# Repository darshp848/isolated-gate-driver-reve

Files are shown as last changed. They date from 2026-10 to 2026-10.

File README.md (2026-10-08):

# Six-channel isolated gate driver — Rev E

An Altium PCB for controlling six floating transistor gates from a low-voltage PWM controller. Each channel has its own isolated bias supply and UCC5310M gate driver; a shared AHCT buffer interfaces the PWM logic. Designed by Darsh Patel, with Claude and Codex assisting the design iteration, layout transfer, review and documentation.

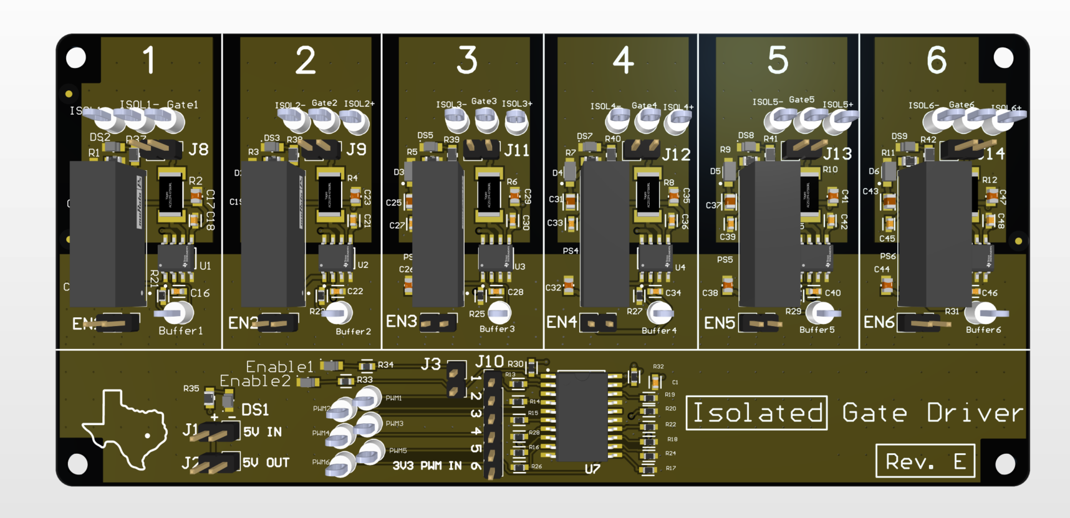
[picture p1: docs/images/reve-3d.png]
Rev E Altium 3D view supplied by Darsh Patel


*Rev E 3D CAD view. Model markings and catalog values may be placeholders; see the component-selection notes below.*

**This is the saved Rev E design snapshot, not a qualified manufacturing release. Some CAD components were selected only for their footprint, schematic symbol and 3D model. Their displayed values, descriptions and manufacturer part numbers are not necessarily the intended electrical parts. Do not order or assemble directly from the exported CAD BOM.** See [component selection and placeholders](docs/component-selection.md).

## Files

| Path | Contents |
| --- | --- |
| `hardware/isolated-gate-driver.PrjPcb` | Standalone Altium project with local document paths |
| `hardware/Sheet2.SchDoc` | Native schematic, unchanged from the source |
| `hardware/PCB2.PcbDoc` | Native four-layer board, silk marked **Rev. E**, unchanged from the source |
| `hardware/libraries/GPIO_Headers.PcbLib` | Project-local 2.54 mm header footprints and models |
| [Architecture](docs/architecture.md) | Signal path, bias supplies, gate drive and design reasoning |
| [Component selection](docs/component-selection.md) | Explicit placeholder examples and commissioning selections |
| [Opening the design](docs/opening-the-design.md) | Altium version, library links and export workflow |
| [Revision and validation](docs/revision-and-validation.md) | What was checked, historical evidence and remaining work |
| [Source manifest](docs/source-manifest.json) | Source-relative paths, modification dates and SHA-256 hashes |
| [Placed footprints](docs/placed-footprints.csv) | Actual footprint names and positions from the saved PCB |

## Status

The snapshot was packaged October 8, 2026, including the user's newly saved Rev E silkscreen correction that day. The schematic was saved October 3. There are 152 unique schematic designators and 155 PCB component records, including three PCB fiducials. Original design binaries are preserved byte-for-byte. Only the project wrapper was adjusted to remove external file paths and references to omitted generated outputs.

October 3 routing/DRC results predate Rev E's October 7–8 edits and do not certify this snapshot. No fresh Altium compile, ECO comparison, repour, DRC or bench qualification was performed for this publication. Old fabrication ZIPs are deliberately excluded; regenerate outputs from the reviewed final design. No complete order-ready Rev E BOM is supplied.

## Purpose

The board separates a controller's PWM commands from six independently referenced gate circuits. It can support experiments with different bridge configurations without putting a processor on the driver board. The external controller and power stage remain responsible for PWM sequencing, dead time, current protection and fault shutdown. Transistor choice, bus voltage, gate charge and switching frequency determine the actual operating envelope.

Functional architecture

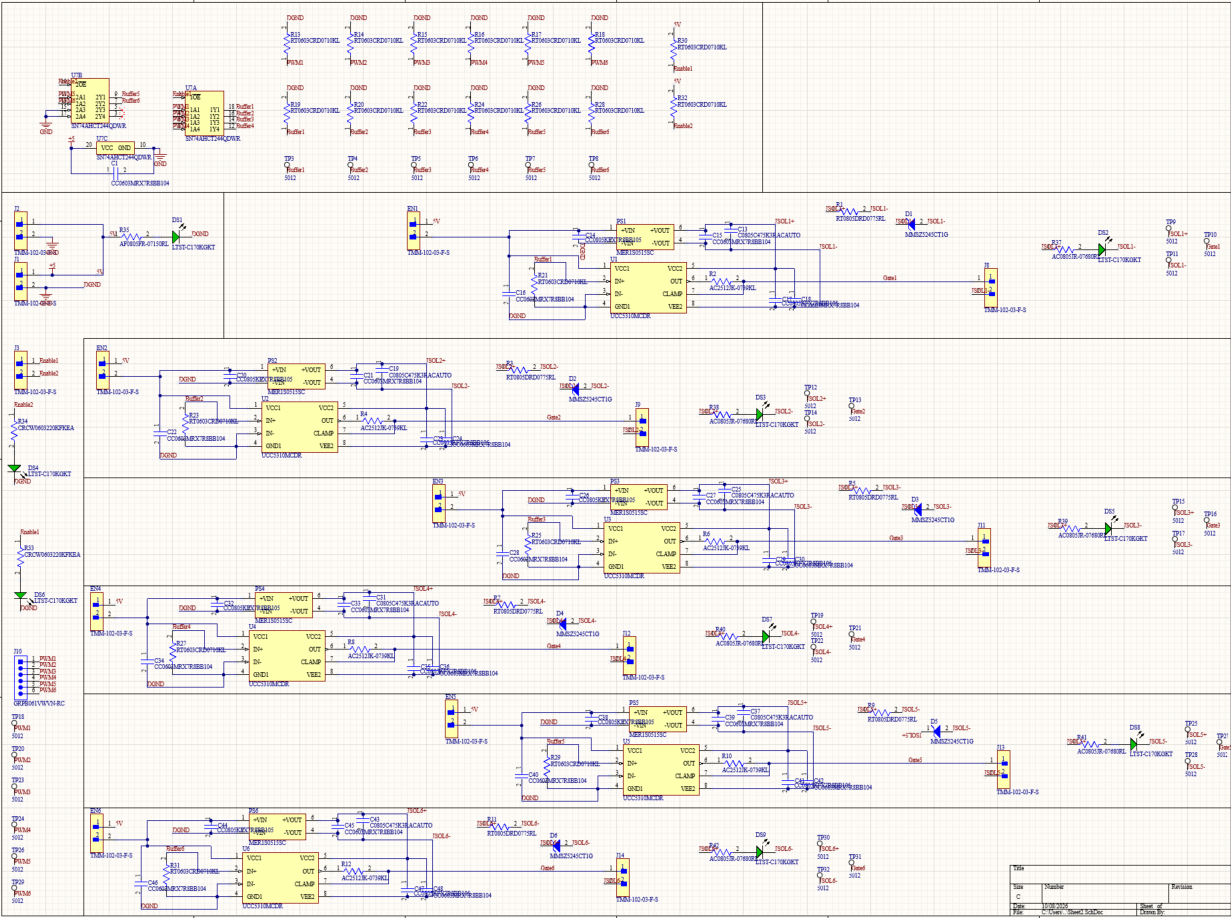
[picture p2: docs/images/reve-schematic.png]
Rev E schematic supplied by Darsh Patel


*Rev E schematic: shared PWM buffer and enable circuitry with six isolated supply and gate-driver channels. Click the image to inspect it at full resolution. Some component values and part numbers are CAD placeholders; use the component-selection notes when interpreting them.*

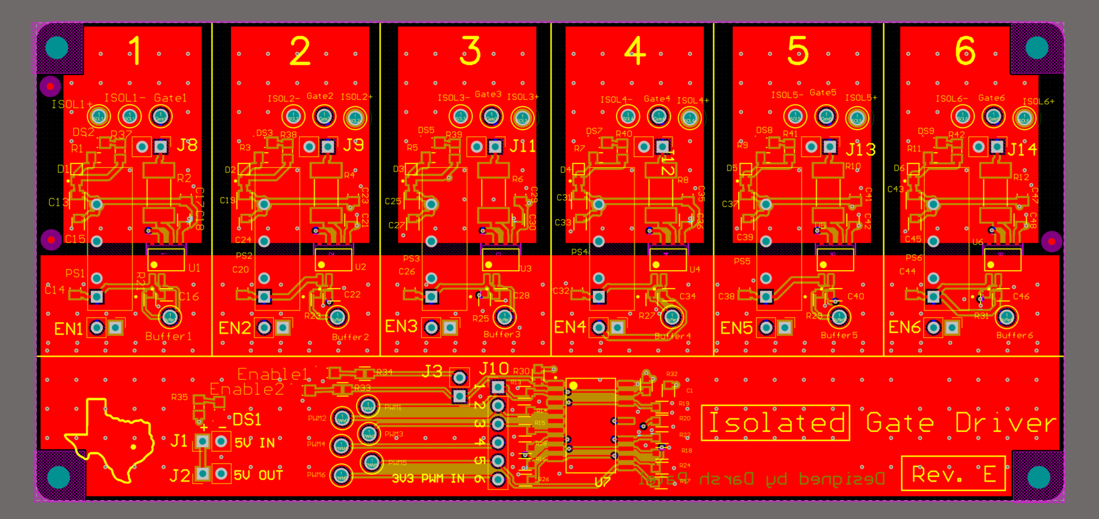
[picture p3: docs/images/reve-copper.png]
Rev E copper and silkscreen view supplied by Darsh Patel


*User-supplied Altium copper view, showing six channel columns and the shared PWM interface. This image is documentation, not a DRC or isolation qualification report.*

The use of isolated driver ICs does not establish an assembled-board safety isolation or working-voltage rating. The converter, PCB stackup, copper spacing, connectors and test arrangement must all meet the intended application. Refer to the [validation record](docs/revision-and-validation.md) before using the design.

## License and attribution

The original circuit/layout contributions and documentation are released under the [MIT license](LICENSE). This grant does not relicense vendor CAD content embedded in the native files. The converted KiCad header library retains its upstream license; see [third-party notices](THIRD_PARTY_NOTICES.md). Manufacturer names identify the parts and do not imply endorsement. AI assistance is documented as development provenance, not evidence of electrical validation.

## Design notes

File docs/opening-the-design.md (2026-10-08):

# Opening and exporting the design

The source workflow used Altium Designer 26; the October layout transfer recorded **26.10.1.5**. Open `hardware/isolated-gate-driver.PrjPcb`. It references the schematic, PCB and local GPIO header library using relative paths.

The original project linked to `../../3-phase-inverter/Sheet2.SchDoc` and `PCB2.PcbDoc`. A much smaller PCB2 file beside the original project was an older/unrelated board. That duplicate is not included. Stale ActiveBOM, PDN analysis, output-job and generated-report entries were removed from the project wrapper. Native schematic and board files were not edited.

Placed symbols, footprints and PCB 3D body data are preserved in the native documents. The header library is included separately for reuse. Some schematic model links still refer to the original machine's library paths or managed component sources; placed content can be inspected, but library update/replacement may require relinking `GPIO_Headers.PcbLib` and obtaining the appropriate upstream vendor libraries. The package does not claim a complete portable library for replacing every part.

Do not run an automatic library update simply to open the design. Resolve intended parts first, especially the metadata/footprint mismatches documented in [component selection](component-selection.md).

## Validation and outputs

Work in a copy of the repository. Compile the project, inspect messages, compare every schematic pin with its PCB pad net, and inspect ECO changes before applying them. Review all four copper layers, isolation-domain spacing, gate loops and return paths. Repour and run fresh native DRC on the final saved board.

Create new output jobs for the reviewed revision: schematic PDF, assembly BOM with DNP flags, pick-and-place file, fabrication drawings, Gerbers and drill files. Inspect the generated layers independently. This snapshot includes no Rev E Gerber release; prior October 4 ZIPs precede the latest board save.

The project organization follows [Altium project documentation](https://www.altium.com/documentation/altium-designer/creating-projects-documents). Output generation remains a separate review step in Altium.

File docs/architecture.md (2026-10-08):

# How the board works

## Signal and supply paths

Six PWM commands enter J10. U7 is an SN74AHCT244 octal non-inverting buffer operated from the control-side 5 V rail. Its TTL-compatible inputs provide an interface for 3.3 V PWM logic; its outputs feed the six UCC5310MCDR IN+ pins. The UCC inputs are CMOS, so using the buffer avoids depending on a marginal direct 3.3 V high level at a 5 V driver input supply. U7 has two independently controlled active-low output-enable banks. See [TI's buffer documentation](https://www.ti.com/product/SN74AHCT244).

Each channel's EN header interrupts the **5 V feed to that channel's driver logic supply and DC/DC converter**. It is a supply-selection jumper, distinct from J3's logic enables. Removing bias power is not a substitute for a characterized fast fault shutdown.

PS1–PS6 are MER1S0515SC unregulated isolated converters. They derive nominal 15 V floating rails from the channel's 5 V input. Each UCC5310 output is referenced to its own ISOLn− return, so the gate output can follow a floating transistor source/emitter. Keep each gate and return together; do not combine isolated returns merely because the connectors look identical.

The series gate resistors control charging/discharging current and switching behavior. The UCC5310M's CLAMP pin connects to the gate-side node after that resistor in the saved schematic diagnostic. Its active Miller clamp is intended to shunt off-state Miller current to the local return. Cable and PCB loop inductance still matter. See [TI's UCC5310 documentation](https://www.ti.com/product/UCC5310).

## Interface map

This map was derived from the **saved October 3 schematic**, using a read-only endpoint/label diagnostic. It is not an Altium-compiled netlist or verification of every October 7 PCB pad. The diagnostic's complete pin groups are in [saved-schematic-pin-groups.json](saved-schematic-pin-groups.json). Confirm the interface against final compiled nets and PCB pads before connecting hardware.

| Connector | Saved schematic connection |
| --- | --- |
| J1, J2 | Pin 1: control 5 V; pin 2: DGND. Parallel access to the same supply. |
| J10 | Pins 1–6: PWM1–PWM6. No control ground pin on this header. |
| J3 | Pin 1: U7 OE1, controlling PWM1–4; pin 2: U7 OE2, controlling PWM5–6. High disables, low enables. |
| EN1–EN6 | Pin 1: shared 5 V; pin 2: corresponding UCC VCC1 and converter +VIN. A shunt supplies that channel. |
| J8, J9 | Pin 1: Gate1/Gate2; pin 2: corresponding ISOL1−/ISOL2−. |
| J11, J12 | Pin 1: Gate3/Gate4; pin 2: corresponding isolated return. |
| J13, J14 | Pin 1: Gate5/Gate6; pin 2: corresponding isolated return. |

R13–R18 pull the PWM inputs toward DGND. Resistors also pull the buffered driver-input commands toward DGND. R30/R32 pull U7's OE nodes toward 5 V; those nodes also feed indicator branches through R33/R34. This is a later schematic change from the September audit, which reported OE bias resistors absent. A controller interface to the 5 V-biased OE pins must be selected and checked for its actual tolerances and power sequencing.

## Bias, indicators and protection footprints

The odd-numbered R1–R11 preloads span each floating rail. The earlier selected 2 kΩ preload draws 7.5 mA and dissipates 0.1125 W at 15 V. This helps maintain a minimum load on an unregulated converter; it is not an inrush limiter or precision regulator. Indicator branches add further rail loading. Their resistor fields also require reconciliation with the assembly selection.

D1–D6 span the isolated rails, cathode toward the positive rail. These optional Zener footprints permit evaluation of rail limiting; their nominal voltage is not a guaranteed transient ceiling. Initial DNP and the proposed 18 V candidate remain documented in [component selection](component-selection.md).

Gate-drive energy per cycle is approximately Qg × Vgate, giving an average gate-charge current near Qg × switching frequency. Converter capacity must cover that demand plus driver quiescent current, preload and indicators. The final resistor also needs pulse and thermal assessment. These estimates guide component selection; they do not establish a tested frequency rating.

The MER1 family has minimum-load and insulation limitations. Its nominal output and isolation test figures must not be treated as a regulated rail specification or whole-board working-voltage rating. Use the [Murata MER1 datasheet](https://www.murata.com/products/productdata/8807029833758/kdc-mer1.pdf) for the selected part and actual application.

## Layout and system responsibilities

The layout uses six repeated channel areas and a common control section on a four-layer board. The October transfer replaced small-pitch catalog header footprints with standard 2.54 mm headers and corrected their 3D-body positions. Preserve actual pad numbering and isolation-domain boundaries when editing.

A short, paired gate/Kelvin-return path reduces ringing and false turn-on risk. Isolation must be reviewed across all copper layers, not just the visible top-layer gap. Controller-side ground, floating channel returns and bench-instrument references need an intentional grounding arrangement.

The PCB contains no processor or autonomous PWM interlock. Dead time, complementary-switch assignment, current sensing, fault shutdown and startup/reset behavior belong to the complete system. An active-low buffer enable is useful command inhibition, but is not a fully qualified power-stage protection scheme.

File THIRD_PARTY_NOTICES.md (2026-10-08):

# Third-party CAD content

The root MIT grant covers Darsh Patel's original design contributions and this repository's documentation. Vendor names, datasheets, catalog parameters, downloaded schematic symbols and embedded CAD/3D models retain their respective owners' rights and terms; no new license is asserted over those assets. Unrelated downloaded-part library collections are not included.

## GPIO header library

`hardware/libraries/GPIO_Headers.PcbLib` is the Altium conversion of KiCad standard `PinHeader_1x02_P2.54mm_Vertical` and `PinHeader_1x06_P2.54mm_Vertical` footprints and associated header models, with model-position corrections made during the Altium transfer. Attribution: KiCad library contributors; Altium conversion/placement corrections during Darsh Patel's project with Codex assistance.

The KiCad library data is distributed under **CC-BY-SA 4.0 with the KiCad electronic-design exception**. Redistribution of library collections retains that license. See [KiCad's license and exception](https://www.kicad.org/libraries/license/) and [CC-BY-SA 4.0 legal text](https://creativecommons.org/licenses/by-sa/4.0/legalcode). The root MIT license does not replace this library license.

Manufacturer documentation is referenced by links, rather than redistributed as datasheet collections.

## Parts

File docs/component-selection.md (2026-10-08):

# Component values, footprints and assembly selection

The schematic and PCB contain parts chosen to obtain a suitable **footprint, schematic symbol or 3D CAD model**. A placeholder may have the correct package but the wrong resistance, power rating, voltage rating, product description or manufacturer part number. A familiar package name is not a component specification.

The native files are published as saved, including this metadata. This repository does not silently rewrite their values or imply that every catalog field is correct.

## Confirmed examples

| References | Metadata retained in CAD | Intended selection or disposition from the design discussions |
| --- | --- | --- |
| R1, R3, R5, R7, R9, R11 | RT0805DRD0775RL; 75 Ω, 0.125 W, 0805 | Rail preload: **2 kΩ, 0.5 W**, ERJ-P06F2001V in the earlier commissioning selection. Verify the final rail load and dissipation. |
| R2, R4, R6, R8, R10, R12 | AC2512JK-0739KL; 39 kΩ, 1 W, 2512 | Gate resistor: **10 Ω, 1 W**, AC2512FK-0710RL as a commissioning starting point. Tune with the actual transistor and switching measurements. |
| U7 | SN74AHCT244QDWR | Earlier procurement selection is SN74AHCT244DWR, DW SOIC-20. Confirm pinout, operating range and footprint for the actual ordered part. |
| D1–D6 | MMSZ5245CT1G, nominal 15 V rail Zener | Earlier procurement proposed MMSZ5248CT1G, nominal 18 V, as a **test candidate**, initially DNP. Neither nominal voltage establishes a safe gate-voltage ceiling. Population remains a qualification decision. |
| J1/J2/J3, J8/J9/J11–J14, EN1–EN6 | Several symbols retain 2 mm header descriptions/MPNs | The placed PCB uses **1×2, 2.54 mm pitch** headers. Order against the actual land pattern and mechanical requirements. |
| J10 | GRPB061VWVN-RC description retains 1.27 mm pitch | The placed PCB uses **1×6, 2.54 mm pitch**. The old symbol's MPN is not a valid purchasing instruction for that footprint. |
| R37–R42 | 680 Ω, 0.125 W indicator-resistor metadata | Later sourcing notes propose 2 kΩ. This is a recommendation requiring assembly reconciliation, not a confirmed populated value. |
| R33/R34 | 220 kΩ indicator-resistor metadata | Later sourcing notes propose 10 kΩ. This is a recommendation; check indicator loading of the OE nodes. |

These are confirmed discrepancies, not an exhaustive approved-parts list. The design also contains indicators and pull/bias components added in later iterations. Their values and exact procurement choices need reconciliation against the complete current schematic.

[CAD metadata CSV](cad-metadata-NOT-FOR-ORDER.csv) is supplied for inspection only. [Placed footprints CSV](placed-footprints.csv) lists the actual saved PCB patterns. Neither file is an approved assembly BOM. Earlier Rev C/D purchase quantities, stock allocation and spare counts have not been carried into this repository as a Rev E order.

## Preparing an assembly BOM

1. Select the actual transistor, its recommended gate voltage, gate charge and operating conditions.
2. Reconcile every designator with its circuit role, desired value, tolerance, voltage/power/pulse rating and population state.
3. Select the actual manufacturer part, then check pin numbering, package dimensions, pad geometry, orientation and 3D body. Matching package size alone is insufficient.
4. Update all schematic parameters and DNP flags, not just visible comments; review the schematic-to-PCB ECO before applying it.
5. Generate a new BOM and compare it by designator with the reviewed assembly plan. Generate fabrication and placement outputs from that same saved revision.

The 2 kΩ preload and 10 Ω gate resistor above are historical commissioning choices. They are not universal choices for every MOSFET, IGBT or SiC device.

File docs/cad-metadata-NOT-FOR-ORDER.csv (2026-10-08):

Designator | CAD comment / MPN (may be placeholder) | CAD description (may be placeholder) | Status
U1 | UCC5310MCDR | DGTL ISO 3KV 1CH GATE DRVR 8SOIC | CAD METADATA ONLY - NOT AN ASSEMBLY BOM
PS1 | MER1S0515SC | Module DC-DC 5VIN 1-OUT 15V 0.067A 1W 4-Pin SIP Tube | CAD METADATA ONLY - NOT AN ASSEMBLY BOM
R21 | RT0603CRD0710KL | RES SMD 10K OHM 0.25% 1/10W 0603 | CAD METADATA ONLY - NOT AN ASSEMBLY BOM
C16 | CC0603MRX7R8BB104 | CAP CER 0.1UF 25V X7R 0603 | CAD METADATA ONLY - NOT AN ASSEMBLY BOM
C14 | CC0805KFX7R8BB105 | CC0805 1 uF X7R 10.00% 25 V | CAD METADATA ONLY - NOT AN ASSEMBLY BOM
C13 | C0805C475K3RACAUTO | CAP CER 0805 4.7UF 25V X7R 10% | CAD METADATA ONLY - NOT AN ASSEMBLY BOM
C15 | CC0603MRX7R8BB104 | CAP CER 0.1UF 25V X7R 0603 | CAD METADATA ONLY - NOT AN ASSEMBLY BOM
C17 | CC0805KFX7R8BB105 | CC0805 1 uF X7R 10.00% 25 V | CAD METADATA ONLY - NOT AN ASSEMBLY BOM
C18 | CC0603MRX7R8BB104 | CAP CER 0.1UF 25V X7R 0603 | CAD METADATA ONLY - NOT AN ASSEMBLY BOM
J10 | GRPB061VWVN-RC | Male Header, Pitch 1.27 mm, 1 x 6 Position, Height 4 mm, Tail Length 2.3 mm, -40 to 105 degC, RoHS, Bulk | CAD METADATA ONLY - NOT AN ASSEMBLY BOM
J8 | TMM-102-03-F-S | CONN HEADER VERT 2POS 2MM | CAD METADATA ONLY - NOT AN ASSEMBLY BOM
J1 | TMM-102-03-F-S | CONN HEADER VERT 2POS 2MM | CAD METADATA ONLY - NOT AN ASSEMBLY BOM
U2 | UCC5310MCDR | DGTL ISO 3KV 1CH GATE DRVR 8SOIC | CAD METADATA ONLY - NOT AN ASSEMBLY BOM
PS2 | MER1S0515SC | Module DC-DC 5VIN 1-OUT 15V 0.067A 1W 4-Pin SIP Tube | CAD METADATA ONLY - NOT AN ASSEMBLY BOM
R23 | RT0603CRD0710KL | RES SMD 10K OHM 0.25% 1/10W 0603 | CAD METADATA ONLY - NOT AN ASSEMBLY BOM
C22 | CC0603MRX7R8BB104 | CAP CER 0.1UF 25V X7R 0603 | CAD METADATA ONLY - NOT AN ASSEMBLY BOM
C20 | CC0805KFX7R8BB105 | CC0805 1 uF X7R 10.00% 25 V | CAD METADATA ONLY - NOT AN ASSEMBLY BOM
C19 | C0805C475K3RACAUTO | CAP CER 0805 4.7UF 25V X7R 10% | CAD METADATA ONLY - NOT AN ASSEMBLY BOM
C21 | CC0603MRX7R8BB104 | CAP CER 0.1UF 25V X7R 0603 | CAD METADATA ONLY - NOT AN ASSEMBLY BOM
C23 | CC0805KFX7R8BB105 | CC0805 1 uF X7R 10.00% 25 V | CAD METADATA ONLY - NOT AN ASSEMBLY BOM
C24 | CC0603MRX7R8BB104 | CAP CER 0.1UF 25V X7R 0603 | CAD METADATA ONLY - NOT AN ASSEMBLY BOM
J9 | TMM-102-03-F-S | CONN HEADER VERT 2POS 2MM | CAD METADATA ONLY - NOT AN ASSEMBLY BOM
U3 | UCC5310MCDR | DGTL ISO 3KV 1CH GATE DRVR 8SOIC | CAD METADATA ONLY - NOT AN ASSEMBLY BOM
PS3 | MER1S0515SC | Module DC-DC 5VIN 1-OUT 15V 0.067A 1W 4-Pin SIP Tube | CAD METADATA ONLY - NOT AN ASSEMBLY BOM
R25 | RT0603CRD0710KL | RES SMD 10K OHM 0.25% 1/10W 0603 | CAD METADATA ONLY - NOT AN ASSEMBLY BOM
C28 | CC0603MRX7R8BB104 | CAP CER 0.1UF 25V X7R 0603 | CAD METADATA ONLY - NOT AN ASSEMBLY BOM
C26 | CC0805KFX7R8BB105 | CC0805 1 uF X7R 10.00% 25 V | CAD METADATA ONLY - NOT AN ASSEMBLY BOM
C25 | C0805C475K3RACAUTO | CAP CER 0805 4.7UF 25V X7R 10% | CAD METADATA ONLY - NOT AN ASSEMBLY BOM
C27 | CC0603MRX7R8BB104 | CAP CER 0.1UF 25V X7R 0603 | CAD METADATA ONLY - NOT AN ASSEMBLY BOM
C29 | CC0805KFX7R8BB105 | CC0805 1 uF X7R 10.00% 25 V | CAD METADATA ONLY - NOT AN ASSEMBLY BOM
C30 | CC0603MRX7R8BB104 | CAP CER 0.1UF 25V X7R 0603 | CAD METADATA ONLY - NOT AN ASSEMBLY BOM
J11 | TMM-102-03-F-S | CONN HEADER VERT 2POS 2MM | CAD METADATA ONLY - NOT AN ASSEMBLY BOM
U4 | UCC5310MCDR | DGTL ISO 3KV 1CH GATE DRVR 8SOIC | CAD METADATA ONLY - NOT AN ASSEMBLY BOM
PS4 | MER1S0515SC | Module DC-DC 5VIN 1-OUT 15V 0.067A 1W 4-Pin SIP Tube | CAD METADATA ONLY - NOT AN ASSEMBLY BOM
R27 | RT0603CRD0710KL | RES SMD 10K OHM 0.25% 1/10W 0603 | CAD METADATA ONLY - NOT AN ASSEMBLY BOM
C34 | CC0603MRX7R8BB104 | CAP CER 0.1UF 25V X7R 0603 | CAD METADATA ONLY - NOT AN ASSEMBLY BOM
C32 | CC0805KFX7R8BB105 | CC0805 1 uF X7R 10.00% 25 V | CAD METADATA ONLY - NOT AN ASSEMBLY BOM
C31 | C0805C475K3RACAUTO | CAP CER 0805 4.7UF 25V X7R 10% | CAD METADATA ONLY - NOT AN ASSEMBLY BOM
C33 | CC0603MRX7R8BB104 | CAP CER 0.1UF 25V X7R 0603 | CAD METADATA ONLY - NOT AN ASSEMBLY BOM
C35 | CC0805KFX7R8BB105 | CC0805 1 uF X7R 10.00% 25 V | CAD METADATA ONLY - NOT AN ASSEMBLY BOM
C36 | CC0603MRX7R8BB104 | CAP CER 0.1UF 25V X7R 0603 | CAD METADATA ONLY - NOT AN ASSEMBLY BOM
J12 | TMM-102-03-F-S | CONN HEADER VERT 2POS 2MM | CAD METADATA ONLY - NOT AN ASSEMBLY BOM
U5 | UCC5310MCDR | DGTL ISO 3KV 1CH GATE DRVR 8SOIC | CAD METADATA ONLY - NOT AN ASSEMBLY BOM
PS5 | MER1S0515SC | Module DC-DC 5VIN 1-OUT 15V 0.067A 1W 4-Pin SIP Tube | CAD METADATA ONLY - NOT AN ASSEMBLY BOM
R29 | RT0603CRD0710KL | RES SMD 10K OHM 0.25% 1/10W 0603 | CAD METADATA ONLY - NOT AN ASSEMBLY BOM
C40 | CC0603MRX7R8BB104 | CAP CER 0.1UF 25V X7R 0603 | CAD METADATA ONLY - NOT AN ASSEMBLY BOM
C38 | CC0805KFX7R8BB105 | CC0805 1 uF X7R 10.00% 25 V | CAD METADATA ONLY - NOT AN ASSEMBLY BOM
C37 | C0805C475K3RACAUTO | CAP CER 0805 4.7UF 25V X7R 10% | CAD METADATA ONLY - NOT AN ASSEMBLY BOM
C39 | CC0603MRX7R8BB104 | CAP CER 0.1UF 25V X7R 0603 | CAD METADATA ONLY - NOT AN ASSEMBLY BOM
C41 | CC0805KFX7R8BB105 | CC0805 1 uF X7R 10.00% 25 V | CAD METADATA ONLY - NOT AN ASSEMBLY BOM
C42 | CC0603MRX7R8BB104 | CAP CER 0.1UF 25V X7R 0603 | CAD METADATA ONLY - NOT AN ASSEMBLY BOM
J13 | TMM-102-03-F-S | CONN HEADER VERT 2POS 2MM | CAD METADATA ONLY - NOT AN ASSEMBLY BOM
U6 | UCC5310MCDR | DGTL ISO 3KV 1CH GATE DRVR 8SOIC | CAD METADATA ONLY - NOT AN ASSEMBLY BOM
PS6 | MER1S0515SC | Module DC-DC 5VIN 1-OUT 15V 0.067A 1W 4-Pin SIP Tube | CAD METADATA ONLY - NOT AN ASSEMBLY BOM
R31 | RT0603CRD0710KL | RES SMD 10K OHM 0.25% 1/10W 0603 | CAD METADATA ONLY - NOT AN ASSEMBLY BOM
C46 | CC0603MRX7R8BB104 | CAP CER 0.1UF 25V X7R 0603 | CAD METADATA ONLY - NOT AN ASSEMBLY BOM
C44 | CC0805KFX7R8BB105 | CC0805 1 uF X7R 10.00% 25 V | CAD METADATA ONLY - NOT AN ASSEMBLY BOM
C43 | C0805C475K3RACAUTO | CAP CER 0805 4.7UF 25V X7R 10% | CAD METADATA ONLY - NOT AN ASSEMBLY BOM
C45 | CC0603MRX7R8BB104 | CAP CER 0.1UF 25V X7R 0603 | CAD METADATA ONLY - NOT AN ASSEMBLY BOM
C47 | CC0805KFX7R8BB105 | CC0805 1 uF X7R 10.00% 25 V | CAD METADATA ONLY - NOT AN ASSEMBLY BOM
C48 | CC0603MRX7R8BB104 | CAP CER 0.1UF 25V X7R 0603 | CAD METADATA ONLY - NOT AN ASSEMBLY BOM
J14 | TMM-102-03-F-S | CONN HEADER VERT 2POS 2MM | CAD METADATA ONLY - NOT AN ASSEMBLY BOM
J2 | TMM-102-03-F-S | CONN HEADER VERT 2POS 2MM | CAD METADATA ONLY - NOT AN ASSEMBLY BOM
R12 | AC2512JK-0739KL | RES SMD 39K OHM 5% 1W 2512 | CAD METADATA ONLY - NOT AN ASSEMBLY BOM
R10 | AC2512JK-0739KL | RES SMD 39K OHM 5% 1W 2512 | CAD METADATA ONLY - NOT AN ASSEMBLY BOM
R8 | AC2512JK-0739KL | RES SMD 39K OHM 5% 1W 2512 | CAD METADATA ONLY - NOT AN ASSEMBLY BOM
R6 | AC2512JK-0739KL | RES SMD 39K OHM 5% 1W 2512 | CAD METADATA ONLY - NOT AN ASSEMBLY BOM
R4 | AC2512JK-0739KL | RES SMD 39K OHM 5% 1W 2512 | CAD METADATA ONLY - NOT AN ASSEMBLY BOM
R2 | AC2512JK-0739KL | RES SMD 39K OHM 5% 1W 2512 | CAD METADATA ONLY - NOT AN ASSEMBLY BOM
U7 | SN74AHCT244QDWR | Automotive Catalog Octal Buffers/Drivers With 3-State Outputs, DW0020A, LARGE T&R | CAD METADATA ONLY - NOT AN ASSEMBLY BOM
D1 | MMSZ5245CT1G | Zener Voltage Regulator, 500 mW, 2-Pin SOD-123, Pb-Free, Tape and Reel | CAD METADATA ONLY - NOT AN ASSEMBLY BOM
R1 | RT0805DRD0775RL | RES SMD 75 OHM 0.5% 1/8W 0805 | CAD METADATA ONLY - NOT AN ASSEMBLY BOM
R3 | RT0805DRD0775RL | RES SMD 75 OHM 0.5% 1/8W 0805 | CAD METADATA ONLY - NOT AN ASSEMBLY BOM
R5 | RT0805DRD0775RL | RES SMD 75 OHM 0.5% 1/8W 0805 | CAD METADATA ONLY - NOT AN ASSEMBLY BOM
R7 | RT0805DRD0775RL | RES SMD 75 OHM 0.5% 1/8W 0805 | CAD METADATA ONLY - NOT AN ASSEMBLY BOM
R9 | RT0805DRD0775RL | RES SMD 75 OHM 0.5% 1/8W 0805 | CAD METADATA ONLY - NOT AN ASSEMBLY BOM
R11 | RT0805DRD0775RL | RES SMD 75 OHM 0.5% 1/8W 0805 | CAD METADATA ONLY - NOT AN ASSEMBLY BOM
D2 | MMSZ5245CT1G | Zener Voltage Regulator, 500 mW, 2-Pin SOD-123, Pb-Free, Tape and Reel | CAD METADATA ONLY - NOT AN ASSEMBLY BOM
D3 | MMSZ5245CT1G | Zener Voltage Regulator, 500 mW, 2-Pin SOD-123, Pb-Free, Tape and Reel | CAD METADATA ONLY - NOT AN ASSEMBLY BOM
D4 | MMSZ5245CT1G | Zener Voltage Regulator, 500 mW, 2-Pin SOD-123, Pb-Free, Tape and Reel | CAD METADATA ONLY - NOT AN ASSEMBLY BOM
D5 | MMSZ5245CT1G | Zener Voltage Regulator, 500 mW, 2-Pin SOD-123, Pb-Free, Tape and Reel | CAD METADATA ONLY - NOT AN ASSEMBLY BOM
D6 | MMSZ5245CT1G | Zener Voltage Regulator, 500 mW, 2-Pin SOD-123, Pb-Free, Tape and Reel | CAD METADATA ONLY - NOT AN ASSEMBLY BOM
J3 | TMM-102-03-F-S | CONN HEADER VERT 2POS 2MM | CAD METADATA ONLY - NOT AN ASSEMBLY BOM
C1 | CC0603MRX7R8BB104 | CAP CER 0.1UF 25V X7R 0603 | CAD METADATA ONLY - NOT AN ASSEMBLY BOM
R13 | RT0603CRD0710KL | RES SMD 10K OHM 0.25% 1/10W 0603 | CAD METADATA ONLY - NOT AN ASSEMBLY BOM
R14 | RT0603CRD0710KL | RES SMD 10K OHM 0.25% 1/10W 0603 | CAD METADATA ONLY - NOT AN ASSEMBLY BOM
R15 | RT0603CRD0710KL | RES SMD 10K OHM 0.25% 1/10W 0603 | CAD METADATA ONLY - NOT AN ASSEMBLY BOM
R16 | RT0603CRD0710KL | RES SMD 10K OHM 0.25% 1/10W 0603 | CAD METADATA ONLY - NOT AN ASSEMBLY BOM
R17 | RT0603CRD0710KL | RES SMD 10K OHM 0.25% 1/10W 0603 | CAD METADATA ONLY - NOT AN ASSEMBLY BOM
R18 | RT0603CRD0710KL | RES SMD 10K OHM 0.25% 1/10W 0603 | CAD METADATA ONLY - NOT AN ASSEMBLY BOM
R30 | RT0603CRD0710KL | RES SMD 10K OHM 0.25% 1/10W 0603 | CAD METADATA ONLY - NOT AN ASSEMBLY BOM
R32 | RT0603CRD0710KL | RES SMD 10K OHM 0.25% 1/10W 0603 | CAD METADATA ONLY - NOT AN ASSEMBLY BOM
R19 | RT0603CRD0710KL | RES SMD 10K OHM 0.25% 1/10W 0603 | CAD METADATA ONLY - NOT AN ASSEMBLY BOM
R20 | RT0603CRD0710KL | RES SMD 10K OHM 0.25% 1/10W 0603 | CAD METADATA ONLY - NOT AN ASSEMBLY BOM
R22 | RT0603CRD0710KL | RES SMD 10K OHM 0.25% 1/10W 0603 | CAD METADATA ONLY - NOT AN ASSEMBLY BOM
R24 | RT0603CRD0710KL | RES SMD 10K OHM 0.25% 1/10W 0603 | CAD METADATA ONLY - NOT AN ASSEMBLY BOM
R26 | RT0603CRD0710KL | RES SMD 10K OHM 0.25% 1/10W 0603 | CAD METADATA ONLY - NOT AN ASSEMBLY BOM
R28 | RT0603CRD0710KL | RES SMD 10K OHM 0.25% 1/10W 0603 | CAD METADATA ONLY - NOT AN ASSEMBLY BOM
TP18 | 5012 | Test Point, White, Through Hole, RoHS, Bulk | CAD METADATA ONLY - NOT AN ASSEMBLY BOM
TP20 | 5012 | Test Point, White, Through Hole, RoHS, Bulk | CAD METADATA ONLY - NOT AN ASSEMBLY BOM
TP23 | 5012 | Test Point, White, Through Hole, RoHS, Bulk | CAD METADATA ONLY - NOT AN ASSEMBLY BOM
TP24 | 5012 | Test Point, White, Through Hole, RoHS, Bulk | CAD METADATA ONLY - NOT AN ASSEMBLY BOM
TP26 | 5012 | Test Point, White, Through Hole, RoHS, Bulk | CAD METADATA ONLY - NOT AN ASSEMBLY BOM
TP29 | 5012 | Test Point, White, Through Hole, RoHS, Bulk | CAD METADATA ONLY - NOT AN ASSEMBLY BOM
TP3 | 5012 | Test Point, White, Through Hole, RoHS, Bulk | CAD METADATA ONLY - NOT AN ASSEMBLY BOM
TP4 | 5012 | Test Point, White, Through Hole, RoHS, Bulk | CAD METADATA ONLY - NOT AN ASSEMBLY BOM
TP5 | 5012 | Test Point, White, Through Hole, RoHS, Bulk | CAD METADATA ONLY - NOT AN ASSEMBLY BOM
TP6 | 5012 | Test Point, White, Through Hole, RoHS, Bulk | CAD METADATA ONLY - NOT AN ASSEMBLY BOM
TP7 | 5012 | Test Point, White, Through Hole, RoHS, Bulk | CAD METADATA ONLY - NOT AN ASSEMBLY BOM
TP8 | 5012 | Test Point, White, Through Hole, RoHS, Bulk | CAD METADATA ONLY - NOT AN ASSEMBLY BOM
TP9 | 5012 | Test Point, White, Through Hole, RoHS, Bulk | CAD METADATA ONLY - NOT AN ASSEMBLY BOM
TP11 | 5012 | Test Point, White, Through Hole, RoHS, Bulk | CAD METADATA ONLY - NOT AN ASSEMBLY BOM
TP12 | 5012 | Test Point, White, Through Hole, RoHS, Bulk | CAD METADATA ONLY - NOT AN ASSEMBLY BOM
TP14 | 5012 | Test Point, White, Through Hole, RoHS, Bulk | CAD METADATA ONLY - NOT AN ASSEMBLY BOM
TP15 | 5012 | Test Point, White, Through Hole, RoHS, Bulk | CAD METADATA ONLY - NOT AN ASSEMBLY BOM
TP17 | 5012 | Test Point, White, Through Hole, RoHS, Bulk | CAD METADATA ONLY - NOT AN ASSEMBLY BOM
TP19 | 5012 | Test Point, White, Through Hole, RoHS, Bulk | CAD METADATA ONLY - NOT AN ASSEMBLY BOM
TP22 | 5012 | Test Point, White, Through Hole, RoHS, Bulk | CAD METADATA ONLY - NOT AN ASSEMBLY BOM
TP25 | 5012 | Test Point, White, Through Hole, RoHS, Bulk | CAD METADATA ONLY - NOT AN ASSEMBLY BOM
TP28 | 5012 | Test Point, White, Through Hole, RoHS, Bulk | CAD METADATA ONLY - NOT AN ASSEMBLY BOM
TP30 | 5012 | Test Point, White, Through Hole, RoHS, Bulk | CAD METADATA ONLY - NOT AN ASSEMBLY BOM
TP32 | 5012 | Test Point, White, Through Hole, RoHS, Bulk | CAD METADATA ONLY - NOT AN ASSEMBLY BOM
TP10 | 5012 | Test Point, White, Through Hole, RoHS, Bulk | CAD METADATA ONLY - NOT AN ASSEMBLY BOM
TP13 | 5012 | Test Point, White, Through Hole, RoHS, Bulk | CAD METADATA ONLY - NOT AN ASSEMBLY BOM
TP16 | 5012 | Test Point, White, Through Hole, RoHS, Bulk | CAD METADATA ONLY - NOT AN ASSEMBLY BOM
TP21 | 5012 | Test Point, White, Through Hole, RoHS, Bulk | CAD METADATA ONLY - NOT AN ASSEMBLY BOM
TP27 | 5012 | Test Point, White, Through Hole, RoHS, Bulk | CAD METADATA ONLY - NOT AN ASSEMBLY BOM
TP31 | 5012 | Test Point, White, Through Hole, RoHS, Bulk | CAD METADATA ONLY - NOT AN ASSEMBLY BOM
R37 | AC0805JR-07680RL | RES SMD 680 OHM 5% 1/8W 0805 | CAD METADATA ONLY - NOT AN ASSEMBLY BOM
R38 | AC0805JR-07680RL | RES SMD 680 OHM 5% 1/8W 0805 | CAD METADATA ONLY - NOT AN ASSEMBLY BOM
R39 | AC0805JR-07680RL | RES SMD 680 OHM 5% 1/8W 0805 | CAD METADATA ONLY - NOT AN ASSEMBLY BOM
R40 | AC0805JR-07680RL | RES SMD 680 OHM 5% 1/8W 0805 | CAD METADATA ONLY - NOT AN ASSEMBLY BOM
R41 | AC0805JR-07680RL | RES SMD 680 OHM 5% 1/8W 0805 | CAD METADATA ONLY - NOT AN ASSEMBLY BOM
R42 | AC0805JR-07680RL | RES SMD 680 OHM 5% 1/8W 0805 | CAD METADATA ONLY - NOT AN ASSEMBLY BOM
R33 | CRCW0603220KFKEA | RES Thick Film, 220kO, 1%, 0.1W, 100ppm/°C, 0603 | CAD METADATA ONLY - NOT AN ASSEMBLY BOM
R34 | CRCW0603220KFKEA | RES Thick Film, 220kO, 1%, 0.1W, 100ppm/°C, 0603 | CAD METADATA ONLY - NOT AN ASSEMBLY BOM
R35 | AF0805FR-07150RL | Anti-Sulfurated Chip Resistor Automotive Grade 150O 1% 0.125W ±100ppm/°C 0805 | CAD METADATA ONLY - NOT AN ASSEMBLY BOM
EN1 | TMM-102-03-F-S | CONN HEADER VERT 2POS 2MM | CAD METADATA ONLY - NOT AN ASSEMBLY BOM
EN2 | TMM-102-03-F-S | CONN HEADER VERT 2POS 2MM | CAD METADATA ONLY - NOT AN ASSEMBLY BOM
EN3 | TMM-102-03-F-S | CONN HEADER VERT 2POS 2MM | CAD METADATA ONLY - NOT AN ASSEMBLY BOM
EN4 | TMM-102-03-F-S | CONN HEADER VERT 2POS 2MM | CAD METADATA ONLY - NOT AN ASSEMBLY BOM
EN5 | TMM-102-03-F-S | CONN HEADER VERT 2POS 2MM | CAD METADATA ONLY - NOT AN ASSEMBLY BOM
EN6 | TMM-102-03-F-S | CONN HEADER VERT 2POS 2MM | CAD METADATA ONLY - NOT AN ASSEMBLY BOM
DS6 | LTST-C170KGKT | Ultra Bright AlInGaP Chip LED, 75 mW, -55 to 85 degC, 2-Pin SMD (0805), RoHS, Tape and Reel | CAD METADATA ONLY - NOT AN ASSEMBLY BOM
DS4 | LTST-C170KGKT | Ultra Bright AlInGaP Chip LED, 75 mW, -55 to 85 degC, 2-Pin SMD (0805), RoHS, Tape and Reel | CAD METADATA ONLY - NOT AN ASSEMBLY BOM
DS9 | LTST-C170KGKT | Ultra Bright AlInGaP Chip LED, 75 mW, -55 to 85 degC, 2-Pin SMD (0805), RoHS, Tape and Reel | CAD METADATA ONLY - NOT AN ASSEMBLY BOM
DS8 | LTST-C170KGKT | Ultra Bright AlInGaP Chip LED, 75 mW, -55 to 85 degC, 2-Pin SMD (0805), RoHS, Tape and Reel | CAD METADATA ONLY - NOT AN ASSEMBLY BOM
DS7 | LTST-C170KGKT | Ultra Bright AlInGaP Chip LED, 75 mW, -55 to 85 degC, 2-Pin SMD (0805), RoHS, Tape and Reel | CAD METADATA ONLY - NOT AN ASSEMBLY BOM
DS5 | LTST-C170KGKT | Ultra Bright AlInGaP Chip LED, 75 mW, -55 to 85 degC, 2-Pin SMD (0805), RoHS, Tape and Reel | CAD METADATA ONLY - NOT AN ASSEMBLY BOM
DS3 | LTST-C170KGKT | Ultra Bright AlInGaP Chip LED, 75 mW, -55 to 85 degC, 2-Pin SMD (0805), RoHS, Tape and Reel | CAD METADATA ONLY - NOT AN ASSEMBLY BOM
DS2 | LTST-C170KGKT | Ultra Bright AlInGaP Chip LED, 75 mW, -55 to 85 degC, 2-Pin SMD (0805), RoHS, Tape and Reel | CAD METADATA ONLY - NOT AN ASSEMBLY BOM
DS1 | LTST-C170KGKT | Ultra Bright AlInGaP Chip LED, 75 mW, -55 to 85 degC, 2-Pin SMD (0805), RoHS, Tape and Reel | CAD METADATA ONLY - NOT AN ASSEMBLY BOM

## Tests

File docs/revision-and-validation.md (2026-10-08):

# Revision provenance and validation boundary

## Publication snapshot — October 8, 2026

The native board contains the text **Rev. E** and was last saved October 8, 2026, at 02:44:43 local time after the user reported a silkscreen correction. The associated Sheet2 schematic was saved October 3. Source paths and SHA-256 hashes are in [source-manifest.json](source-manifest.json). The schematic has 152 unique designators; the board has 155 component records, including three additional fiducials. Equal counts would not prove connectivity; these counts are inventory evidence only.

The publication check read the saved binary documents, confirmed revision text and footprint patterns, identified the project's actual linked files, and compared copied-file hashes. All project document paths resolve inside the repository. This was packaging and documentation, not a fresh CAD or hardware acceptance test.

The copper and 3D illustrations were supplied by Darsh Patel during publication and visibly identify Rev E. They precede the newly reported silkscreen correction and are not regenerated outputs tied to the source hashes. An offline diagnostic of the current saved schematic resolved 344 pin endpoints into 57 groups, including the gate-side clamp, OE pullups and EN supply jumpers. That diagnostic does not replace native compilation or a current PCB pad-net comparison.

## Earlier development

- Rev C review identified direct 3.3 V PWM threshold concerns, light-load bias-supply behavior, clamp wiring, gate-loop length and isolation-layout issues.
- Rev D iteration added an AHCT buffer, preload and optional rail-clamp footprints; earlier saved-schematic review confirmed CLAMP connects to the gate after the series resistor. Component metadata still included package-selection placeholders.
- October 2–3 work transferred a KiCad placement/routing proposal to Altium and replaced sixteen headers with standard 2.54 mm footprints. Header 3D-body offsets were corrected. The reference KiCad proposal was a development aid, not an independently maintained Rev E release.
- October 3 native DRC recorded no shorts, unrouted nets or electrical clearance violations in that saved revision, while hundreds of silkscreen violations remained. These results predate subsequent edits and are not a Rev E pass.
- October 7 conversation records the user removing a redundant L4 same-net loop near R25/C28. Same-net loops can pass connectivity and short-circuit checks. The saved project instructions now require a visual copper review on every routed layer.

The documentation was reconciled with local Claude and Codex session history and saved review/transfer notes. Raw sessions are not published: they contain unrelated work and machine-specific context. Historical AI claims of generic operating voltage or switching-frequency limits are not carried forward as validated specifications.

## Before fabrication or energized use

Resolve the assembly BOM and all DNP choices. Compile and verify every connector, enable, buffer and driver pin against final pad nets. Inspect all copper layers and changed routes for loops, stubs, unexpected branches, return-path discontinuities and copper overlap between voltage domains. Repour and run final native DRC, recording tool version, exact file hashes, date and remaining dispositions.

No assembled-board working-voltage certification, transistor-independent switching-frequency rating or measured operating envelope is established here. Review the complete insulation path and converter limitations for the intended system. Bring-up should separate unpowered continuity, bias-only startup/idle/load behavior, logic/dummy-load testing, and actual transistor switching tests. The external power stage needs defined dead time and fault shutdown. Probe each floating gate relative to its own source/Kelvin return with suitable measurement equipment.

Record measured gate peaks, off-state transients, delay/overlap, rail behavior and temperatures with the transistor MPN, bus voltage, gate charge, frequency and duty range. These measurements remain separate from CAD verification.

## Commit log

2026-10-08 Publish isolated gate driver Rev E source and design documentation
    [PCB2.PcbDoc, Sheet2.SchDoc, cad-metadata-NOT-FOR-ORDER.csv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]
2026-10-08 Refresh Rev E snapshot after latest saved silkscreen correction
    [PCB2.PcbDoc]
2026-10-08 Show Rev E schematic in README
